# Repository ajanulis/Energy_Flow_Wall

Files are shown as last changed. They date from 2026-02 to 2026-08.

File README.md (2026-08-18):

# Energy Flow Wall (Public)

Public hardware/reference repository for the Energy Flow Wall mesh-networked
ventilation valve system, organized by subsystem:

```
Actuator/   Window-frame-mounted valve unit — KiCad PCB designs, Fusion 360 case, manuals
Gateway/    Raspberry Pi + NC1000 mesh gateway — NeoCortec protocol docs
Device/     In-room e-paper touchscreen — hardware planning, procurement, datasheets, working-prototype photos
Docs/       Whole-system docs (functional requirements, architecture reference)
```

Source code (firmware, Gateway pipeline, Node-RED deploy scripts) is
maintained in a separate private repository.

---

## Actuator

The window-frame-mounted unit itself — PSoC5 + NC1000 mesh radio + motors + flaps + fan.

- [`Actuator/KiCad/`](Actuator/KiCad/) — PCB designs.
- [`Actuator/Actuator_EFW#4_based_on_8411A v4_non_symmetrical_case.f3d`](<Actuator/Actuator_EFW%234_based_on_8411A%20v4_non_symmetrical_case.f3d>) — Fusion 360 mechanical design (non-symmetrical case, v4). Open with Autodesk Fusion 360; all parametric history included. [Direct download](<https://github.com/ajanulis/Energy_Flow_Wall/raw/main/Actuator/Actuator_EFW%234_based_on_8411A%20v4_non_symmetrical_case.f3d>).
- [`Actuator/Manuals/DK_USER_MANUAL.md`](Actuator/Manuals/DK_USER_MANUAL.md) — End-user manual for the shipped demo unit: setup, dashboard usage, Demo Mode, troubleshooting.
- [`Actuator/Manuals/COMMANDS.md`](Actuator/Manuals/COMMANDS.md) — Developer/integrator reference: MQTT topics, JSON request format, full firmware command set, timeouts.

**Hardware**: PSoC 5 (CY8C5888LTQ-LP097) · DRV8411A motor driver · NC1000 mesh radio · UART 115200 baud.

## Gateway

Raspberry Pi 5 + NC1000 daughterboard, running NeoGateway + Node-RED +
the MQTT⇌mesh pipeline.

- [`Gateway/KiCad/Gateway_PCB/`](Gateway/KiCad/Gateway_PCB/) — the RPi/NC1000 HAT PCB design (moved here from `Actuator/KiCad/`, where it was previously grouped by mistake).
- [`Gateway/NeoCortec/`](Gateway/NeoCortec/) — NeoCortec integration manual, NC1000 datasheet, and UART communication spec — the protocol reference the Gateway pipeline implements against.

## Device

In-room e-paper touchscreen display. Custom PCB is still in the planning
stage, but a working touchscreen dashboard already runs end-to-end on an
STM32U5 Nucleo — see [`Device/README.md`](Device/README.md) for photos
and a walkthrough of what it does.

- [`Device/README.md`](Device/README.md) — working-prototype photos + what it does. **Start here.**
- [`Device/Brief.md`](Device/Brief.md) — architectural decisions + concept/scope.
- [`Device/Procurement.md`](Device/Procurement.md), [`Device/Datasheet_Stash.md`](Device/Datasheet_Stash.md) — parts sourcing and reference datasheets.
- [`Device/HW_Prep.md`](Device/HW_Prep.md), [`Device/Doc_Gaps.md`](Device/Doc_Gaps.md) — bring-up prep notes and known documentation gaps.

## Docs (whole-system)

- [`Docs/SYSTEM_REFERENCE.md`](Docs/SYSTEM_REFERENCE.md) — high-level system reference (architecture, mesh layout).
- [`Docs/EFW_Functional_Requirements_1.md`](Docs/EFW_Functional_Requirements_1.md) — original functional requirements document.

---

**Questions?** Contact the repository owner.

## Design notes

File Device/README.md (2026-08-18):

# Device — In-Room User-Facing Mesh Node

This directory holds the design intent, prep work, procurement notes, and
working-prototype progress for the **EFW Device** — the third node type
in the Energy Flow Wall mesh, alongside the Gateway (RP5 + NeoGW) and the
Actuator (flap motors).

**Status:** custom PCB not yet designed (all schematic decisions are
locked at the architectural level, PCB layout is the next step), but a
working touchscreen dashboard is already running end-to-end on an
STM32U5 Nucleo dev board over the real mesh — see below.

## Working prototype

| Auto mode | Manual override |
|---|---|
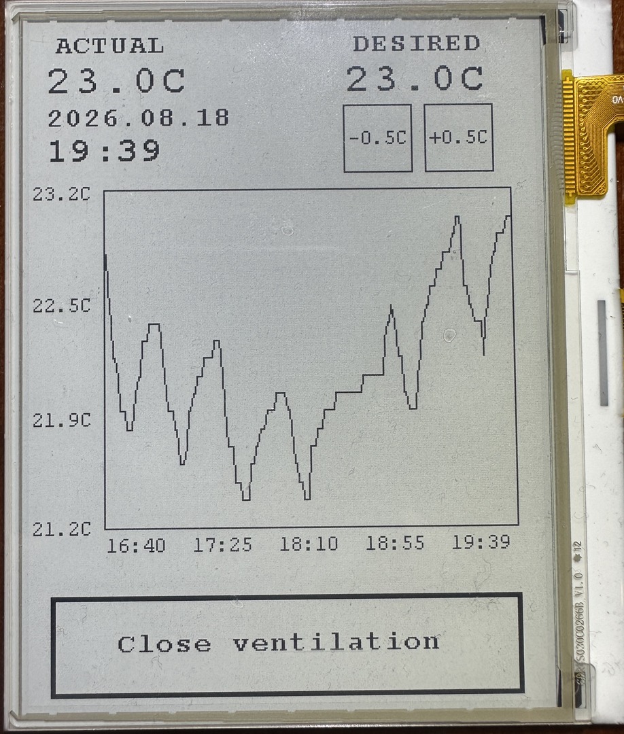
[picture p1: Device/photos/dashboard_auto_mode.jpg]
Dashboard in auto mode
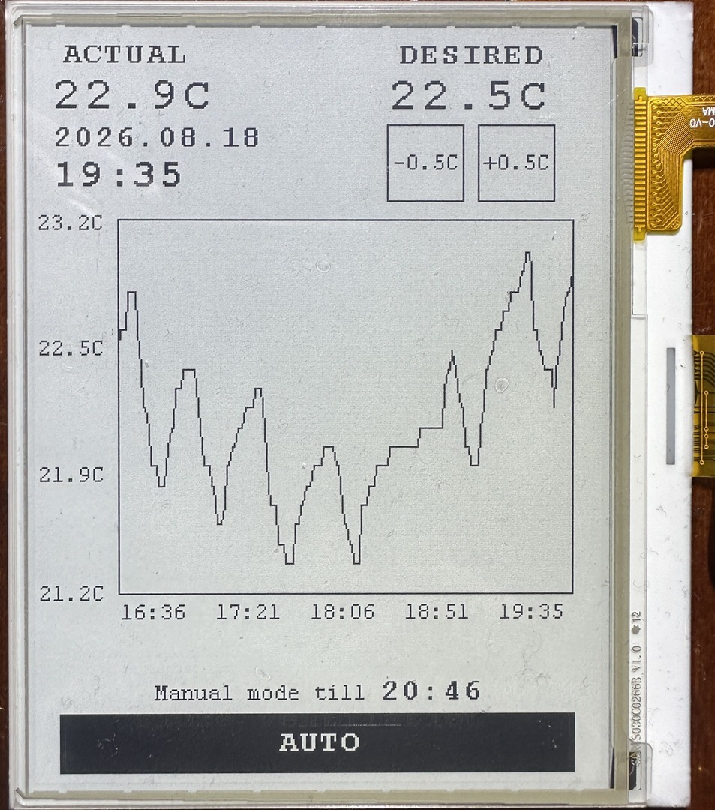
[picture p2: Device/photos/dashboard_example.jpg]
Dashboard in manual mode
|  |  |
| Valve following its normal schedule — tall **"Close ventilation"** button offers to override it. | A manual override active (here, from a DESIRED nudge) — short **"AUTO"** button, with the till-time shown, cancels it. |

A 4.2" e-paper touchscreen (GDEY042T81, FT6336U touch) on an STM32U5
Nucleo, talking to the mesh over a NeoCortec NC1000 radio. In-room
display + manual override panel for one valve zone — no phone or laptop
needed to see the current temperature or flip into manual mode.

**What it shows:**
- **ACTUAL** — the room's current temperature, live from the mesh.
- **DESIRED** — the target temperature; tap `-0.5C` / `+0.5C` to nudge it.
- **Date / time** — synced live, every ~30s.
- **Chart** — a live temperature history kept on-device: tap the top of
  the chart to zoom out (3h → 6h → 12h → 24h → 48h → 7d), the bottom to
  zoom back in, and the left/right halves to scroll back/forward in time.
- **Valve button** — the black bar along the bottom, showing either
  "Close ventilation" (Auto mode) or "AUTO" + a manual-override till-time.

Firmware source, build/flash instructions, and a fuller writeup live in
the private code repo (see below) — this directory is progress notes and
photos only.

## What the Device is

A battery-powered in-room sensor and user-interface node:

- 4.2" 400×300 monochrome e-paper with bonded capacitive touch overlay (GoodDisplay GDEY042T81-T02 + FT6336U)
- STM32U585 (ARM Cortex-M33 @ 160 MHz, 2 MB flash)
- NeoCortec NC1000 sub-GHz mesh + Bluetooth Low Energy
- Modular sensor population per install: temperature / humidity always (Sensirion SHT45), CO₂ optional (Sensirion SCD41), human presence optional (Infineon BGT60LTR11AIP 60 GHz radar), 2 in / 2 out potential-free I/O optional
- LiFePO₄ pouch battery (LFP143060, 1800 mAh) with MagSafe wireless charging (TI BQ51013B)
- Optional accessory: small solar panel + TI BQ25570 MPPT energy harvester

The Device replaces the retired 0x33 / 0x44 NC1000-only test-only T/H sniffers.

## Files in this directory

| File | What's in it |
|---|---|
| [Brief.md](Brief.md) | Architectural decisions — display, power, sensors / I/O, mesh integration, all locked component choices and the rationale. **Read this first.** |
| [Schematic_placeholder.md](Schematic_placeholder.md) | Authoritative-schematic file (placeholder until hardware exists). |
| [HW_Prep.md](HW_Prep.md) | Toolchain setup, reading order for the datasheets, and the firmware skeleton work that can be done without hardware in hand. |
| [Procurement.md](Procurement.md) | Tiered dev-kit shopping list with prices and rationale. |
| [Doc_Gaps.md](Doc_Gaps.md) | Datasheet gaps still to grab + TBD part choices that block the schematic. |
| [Datasheet_Stash.md](Datasheet_Stash.md) | Pointer to the local datasheet stash (path is on the author's machine; the third-party PDFs themselves are not in this repo). |
| [LFP_Pouch_Sources.md](LFP_Pouch_Sources.md) | Verified LFP pouch cell suppliers for the Device battery. |
| [Sniffer_Concept.md](Sniffer_Concept.md) | Exploratory concept for a future mains-powered premium air-quality variant on the same mesh. Not yet committed. |
| `scripts/grab_datasheets.py` | Idempotent downloader for the Device datasheets. |
| `scripts/DOWNLOADS_TODO.md` | List of files that need to be downloaded manually (gated PDFs, login walls, CDN-fighting-curl, etc.). |
| [`Docs/02_Display_Touch/READ_FIRST.md`](Docs/02_Display_Touch/READ_FIRST.md) | Porting strategy for the GoodDisplay GDEY042T81-T02 reference firmware (STM32F103) to the STM32U585 production target. |
| `Docs/DOWNLOADS_TODO.html` | HTML rendering of `scripts/DOWNLOADS_TODO.md`. |

The `Docs/` subdirectory holds annotations about external reference materials kept locally; the third-party datasheets and vendor sample-code archives themselves are not in this repo for licensing and repo-size reasons.

## Sibling content in this repo

- [`../Actuator/KiCad/Main_PCB_Based_on_8411A/`](../Actuator/KiCad/Main_PCB_Based_on_8411A/) — the Actuator KiCad design (sibling node, useful reference).
- [`../Docs/`](../Docs/) — system-level documentation (SYSTEM_REFERENCE, EFW_Functional_Requirements, etc.).
- [Energy_Flow_Wall_Code](https://github.com/ajanulis/Energy_Flow_Wall_Code) — private firmware + scripts repo; Device firmware (build/flash instructions, full technical writeup) lives there under `firmware/device/epaper_bringup/`.

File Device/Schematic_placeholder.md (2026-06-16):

# Device Schematic — Authoritative Reference (PLACEHOLDER)

**Status: hardware not yet designed.** Nothing in this file is ground truth yet.

When the Device PCB + MCU TopDesign exist, this file gets populated the same way `schematic-actuator` (internal note) was — written page-by-page from the actual PDF schematic together with Aidas. Do NOT infer schematic topology from code, synthesis reports, or assumptions — only from the PDF or Aidas confirmation.

Until then, design intent lives in [Brief](Brief.md). Open hardware questions to resolve before this file can be written:

- ~~MCU choice~~ — **decided 2026-06-15**: STMicroelectronics **STM32U585CIU6** (QFN-48, Cortex-M33 @ 160 MHz, 2 MB flash, 786 KB RAM). See `device_brief.md` for rationale. Schematic will document final peripheral pin assignments (SPI for e-paper + radar, I²C for SCD41 + GT911 touch, USART for NC1000 CTS-wake, GPIO for opto-in / MOSFET-out, ADC for battery monitor).
- E-paper panel model + controller + SPI pin map + refresh timing
- CO₂ sensor candidate (SCD41 / SCD30 / SGP41) and its I²C bus sharing with SHT45
- Presence sensor type (PIR binary vs. mmWave continuous)
- Potential-free I/O channel count, isolation, max voltage/current
- Touch button mechanism (cap-touch direct to MCU vs. dedicated controller)
- LiFePO₄ pack: cell count, BMS, charge current, MagSafe coil + receiver IC selection
- Solar input topology (when populated) and its interaction with the wireless-charge path
- Magnet layout for MagSafe alignment + how it coexists with NC1000 antenna routing

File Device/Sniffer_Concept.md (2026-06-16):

# Sniffer — Future Premium Air-Quality Variant (EXPLORATORY)

**Status: concept only.** Not yet a committed product. Captured here so the idea isn't lost when the [Brief](Brief.md) decided "SCD41 only, leave full AQ out of the Device base SKU".

## Role
Standalone indoor air-quality monitor that joins the same NC1000 mesh as Device, Actuator, and Gateway. Use case: rooms where the customer wants full IAQ visibility (PM, VOC, NOx in addition to CO₂ + T/H), and where that data can also influence flap behavior on the Actuator via the Gateway.

Distinct from Device because:
- **Mains-powered** — no LiFePO₄ / MagSafe constraints, so fan-driven sensors are fine.
- **AQ-first** — display may or may not be present; the value-add is the sensor suite, not the user interface.
- **Different enclosure mechanics** — needs intake/exhaust airflow paths.

## Sensors (initial concept)
- **Sensirion SEN6x** — combined module covering CO₂ + T + RH + VOC + NOx + PM. Exact variant (SEN66 with CO₂, SEN65 without, SEN63C without NOx) TBD by feature target.
- **Bosch BMV080** — optional. **Fan-less laser PM1/PM2.5 sensor** (no moving air required). Could either replace SEN6x PM (run SEN6x fan-disabled for the gas sensors only, use BMV080 for PM) — quieter, lower power, smaller enclosure — or run alongside as redundancy. Decide based on power-vs-accuracy testing.

## Power & enclosure
- Mains-powered (USB-C PD or barrel jack TBD).
- Continuous operation, no aggressive sleep.
- Enclosure must accommodate fan airflow if SEN6x is the PM source. If BMV080 replaces PM in SEN6x, fan can stay off → much quieter, smaller enclosure possible.

## Mesh integration
- Same NC1000 + AAPI as Device and Actuator.
- New node-ID class TBD.
- Reports periodic AQ readings to Gateway in Normal mode. Could accept commands in ALT mode (e.g. force-measurement, calibration).

## Open questions (don't burn cycles on these until Device is shipping)
1. Is Sniffer a separate PCB or a populate-variant of the Device PCB? Device PCB already has PSoC6 + NC1000 + display + CapSense — adding SEN6x + BMV080 as a populate option could keep the SKU count low. But airflow paths in the Device enclosure may be incompatible with the wall-flush aesthetic, forcing a separate enclosure.
2. Does Sniffer need its own display, or just a status LED?
3. SEN6x variant choice — SEN66 (with CO₂) vs SEN65 (without, paired with separate SCD41) vs SEN63C (no NOx).
4. BMV080 — confirmed availability, evaluation board, accuracy vs SEN6x PM at low duty cycle, power figures from datasheet.

## Linked
- [Brief](Brief.md) — the base SKU that this product extends
- `schematic-actuator` (internal note) — reference for what an authoritative schematic file should look like

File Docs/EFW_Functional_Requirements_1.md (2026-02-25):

# Energy Flow Wall (EFW) — Functional Requirements Document

**Version:** 0.8  
**Last Updated:** 2026-02-24  
**Status:** Draft

---

## 1. System Overview

The Energy Flow Wall (EFW) is a smart building ventilation system designed to automate ventilation valves for energy-efficient airflow control. The valves are incorporated into the top sash of the window and controlled by motorised actuators. The system uses a wireless mesh network to coordinate actuator nodes, enabling automated and remote control of valve positions to optimise indoor air quality, thermal comfort, and energy consumption. Efficacy testing has been conducted by the Fraunhofer Institute (Germany) and Aalborg University (Denmark).

---

## 2. Architecture

### 2.1 Network Topology

- **Mesh Protocol:** NeoCortec NC1000 mesh networking
- **Gateway:** NeoGateway software running on Raspberry Pi 5, hardwired to one NC1000 module
- **Node Types:** Actuator nodes, Device nodes

```
[Raspberry Pi 5 + NeoGateway]
        |
    [NC1000] ─── (mesh) ─── [NC1000] ─── [NC1000]
                               |               |
                          [PSoC CY8C5888]  [Device Node]
                          [Motor A] [Motor B]
```

### 2.2 Node Types

#### 2.2.1 Gateway Node
- **Hardware:** Raspberry Pi 5 in Argon One V5 Casted Aluminium case
- **Storage:** 256 GB NVMe SSD via Argon NVMe expansion board (faster boot, more reliable than microSD)
- **Wireless module:** NeoCortec NC1000-8 (868 MHz), external antenna mounted on Argon One V5 case
- **Display:** External mini OLED — shows IP address, CPU temperature, CPU core loads, memory utilisation
- **UPS:** Argon One V5 UPS planned (listed in Argon manuals, not yet available to order)
- **Software:** NeoGateway, Node-RED (automation logic), MQTT (message broker), Grafana (monitoring/visualisation)
- **Role:** Bridge between mesh network and higher-level control/monitoring systems
- **Interfaces:** UART to NC1000-8, Ethernet/WiFi for upstream connectivity

#### RPi ↔ NC1000-8 Wiring (4-wire)

| Signal | RPi 40-pin Header Pin |
|---|---|
| NC1000 nReset | Pin 18 |
| NC1000 RX | Pin 24 |
| NC1000 TX | Pin 21 |
| NC1000 CTS | Pin 19 |

#### 2.2.2 Actuator Node
- **Hardware:** NC1000 + Cypress CY8C5888LTQ PSoC
- **Interface:** NC1000 to PSoC via UART — 3 signals: **RX, TX, CTS**. CTS used as wake signal for PSoC and as ready-to-communicate indicator from NC1000
- **Role:** Dual motor control for window flaps + fan PWM control
- **Motors:** 2 per node (Motor A, Motor B) — rotate flaps to open/close air pathways
- **Fan:** PWM-controlled via Port 3
- **Feedback:** Quadrature encoder per motor
- **Protection:** Overcurrent detection per motor
- **Power:** Battery-powered; PSoC in deep sleep during Normal mode, wakes on UART activity

#### 2.2.3 Device Node
- **Hardware:** TBD
- **Role:** TBD (sensors, switches, or other peripherals)

---

## 3. Functional Requirements

### 3.1 Gateway

| ID | Requirement | Priority | Status |
|----|---|---|---|
| GW-01 | Gateway shall receive and forward commands from upstream system to mesh nodes | High | Draft |
| GW-02 | Gateway shall relay status/telemetry from mesh nodes to upstream system | High | Draft |
| GW-03 | Gateway shall maintain persistent UART connection to local NC1000 module | High | Draft |
| GW-04 | Gateway shall support reconnection on UART failure | Medium | Draft |
| GW-05 | Gateway shall log mesh traffic for diagnostics | Low | Draft |

### 3.2 Actuator Node

| ID | Requirement | Priority | Status |
|----|---|---|---|
| AC-01 | Actuator shall receive motor commands via NC1000 wireless mesh | High | Draft |
| AC-02 | Actuator shall control two independent motors (Motor A, Motor B) via DRV8411A | High | Draft |
| AC-03 | Actuator shall track motor position using quadrature encoder feedback | High | Draft |
| AC-04 | Actuator shall detect and respond to overcurrent conditions per motor | High | Draft |
| AC-05 | Actuator shall report actual motor positions back through mesh after movement | High | Draft |
| AC-06 | Actuator shall execute position commands with configurable speed/ramp | Medium | Draft |
| AC-07 | Actuator shall support emergency stop command | High | Draft |
| AC-08 | Actuator shall retain last known motor positions on power cycle | Medium | Draft |
| AC-09 | PSoC shall remain in deep sleep during Normal mode | High | Draft |
| AC-10 | PSoC shall wake on CTS pin assertion by NC1000 | High | Tested |
| AC-11 | PSoC shall transmit current motor positions immediately on wake | High | Draft |
| AC-12 | PSoC shall not transmit to NC1000 until CTS is asserted | High | Tested |
| AC-13 | Actuator shall accept and execute fan PWM control commands | Medium | Draft |
| AC-14 | Actuator shall report position even if target not reached (mechanical fault) | High | Draft |

### 3.3 Device Node

| ID | Requirement | Priority | Status |
|----|---|---|---|
| DV-01 | TBD | - | Draft |

---

## 4. Communication Protocol

### 4.1 Physical Layer

- **Gateway ↔ NC1000:** UART (hardwired)
- **PSoC ↔ NC1000:** UART (hardwired), AAPI protocol
- **NC1000 ↔ SHT45:** Native NC1000 interface (no PSoC involvement)
- **Node ↔ Node:** NC1000 wireless mesh (NeoCortec proprietary)

### 4.2 Node ID Scheme

| Node Type | Node ID (Hex) |
|---|---|
| Gateway | 0x0010 |
| Actuator 1 | 0x0011 |
| Actuator 2 | 0x0012 |
| Actuator N | 0x0010 + N |
| Device nodes | TBD |

### 4.3 Mesh Operating Modes

### 4.3 Mesh Operating Modes

#### Normal Mode
- NC1000 on each node autonomously reads T & H data from SHT45
- Data is periodically transmitted to Gateway (Node ID 0x0010)
- PSoC is in deep sleep (power preservation — battery-powered nodes)
- Applies to both Actuator and Device nodes
- Future: CO2 sensor data to be added

#### Alternative Mode
- **Trigger:** Initiated by Gateway when monitored environmental thresholds are exceeded:
  - Temperature exceeds set limit, OR
  - Humidity exceeds set limit
  - Future: CO2 level exceeds set limit
- **Scope:** Entire mesh switches mode simultaneously (not per-node)

- **Activation sequence:**
  1. Gateway broadcasts switch to Alternative mode — entire mesh transitions
  2. NC1000 switches to UART mode on all nodes
  3. PSoC wakes up (triggered by NC1000 UART activity)
  4. On wake-up, PSoC immediately transmits current motor positions via UART ports
  5. PSoC parses incoming commands from Gateway:
     - New motor position commands (Motor A, Motor B)
     - Fan PWM level command
  6. PSoC executes received commands (motor movement, fan adjustment)
  7. Actuator reports actual achieved motor positions back to Gateway
     - Position may differ from commanded if mechanical obstruction or failure occurred
  8. Gateway switches entire mesh back to Normal mode
  9. PSoC returns to deep sleep
  10. Nodes resume periodic T & H (and future CO2) data collection

- **Timeout / retry handling:**
  - If Gateway does not receive motor position report after command, it waits 10 seconds
  - After 10 seconds, Gateway re-initiates Alternative mode (NC1000 switches to UART again)
  - PSoC waking up on UART activity should be sufficient to trigger position retransmission

#### Mode Transition Diagram
```
[Normal Mode] ──── threshold exceeded ────► [Alternative Mode]
    ▲                                              │
    │                                   NC1000 → UART mode
    │                                   PSoC wakes up
    │                                   PSoC sends positions
    │                                   Gateway sends commands
    │                                   Motors/Fan move
    │                                   PSoC reports positions
    │                                              │
    │         no response? wait 10s, retry Alt ───►│
    │                                              │
    └──────────── Gateway resets to Normal ────────┘
```

#### PSoC Power Management
- PSoC is in deep sleep during Normal mode (battery-powered)
- **Wake signal: CTS pin** — NC1000 asserts CTS when it transitions to UART mode (Alternative mode entry)
- PSoC ↔ NC1000 physical interface: **3 signals — RX, TX, CTS**
- On wake: PSoC immediately transmits current motor positions, then parses incoming commands
- Return to sleep: when mesh returns to Normal mode

> **Note:** NC1000 also sleeps most of the time and will not respond to any commands until it wakes up and asserts CTS. CTS must be monitored before any UART transmission is attempted in both directions — PSoC must not transmit until CTS is asserted by NC1000.

#### NC1000 UART Port Assignment

| Port | Assignment |
|---|---|
| Port 0 | Reserved |
| Port 1 | Motor A position |
| Port 2 | Motor B position |
| Port 3 | Fan PWM control |

### 4.4 AAPI Protocol (NC1000 ↔ PSoC)

- Protocol used for communication between NC1000 module and PSoC firmware
- Commands received by NC1000 are forwarded to PSoC via AAPI over UART
- Known issue: "one packet delay" — response to a command arrives one packet late; must be accounted for in parsing logic
- AAPI parsing must handle complete packet detection before command execution

### 4.5 Command Reference

| Command | Direction | Description | Status |
|---|---|---|---|
| MOTOR_A_MOVE | Gateway → Actuator | Move Motor A to target position | Draft |
| MOTOR_B_MOVE | Gateway → Actuator | Move Motor B to target position | Draft |
| MOTOR_STOP | Gateway → Actuator | Emergency stop both motors | Draft |
| STATUS_REQ | Gateway → Actuator | Request current actuator status | Draft |
| STATUS_RESP | Actuator → Gateway | Motor positions, states, faults | Draft |

*(To be expanded)*

---

## 5. Hardware Reference

### 5.1 Key Components

| Component | Part | Role |
|---|---|---|
| Microcontroller | Cypress CY8C5888LTQ (PSoC 5LP) | Motor control, encoder reading, fault detection |
| Wireless module (Actuator/Device) | NeoCortec NC1000 | Mesh networking + native SHT45 interface |
| Wireless module (Gateway) | NeoCortec NC1000-8 (868 MHz, external antenna) | Mesh gateway radio |
| T&H Sensor | Sensirion SHT45 | Temperature & humidity, read natively by NC1000 |
| Motor driver | Texas Instruments DRV8411A | Dual H-bridge motor drive |
| Gateway hardware | Raspberry Pi 5 + Argon One V5 case + NVMe 256 GB | NeoGateway host |
| Gateway software | NeoGateway | Mesh-to-upstream bridge |
| Gateway display | Mini OLED | Local diagnostics (IP, CPU temp, load, memory) |

### 5.2 PSoC Peripherals Used

- Dual PWM for motor drive
- Quadrature Decoder (x2) for encoder feedback
- UART for NC1000 communication
- ADC or comparator for overcurrent sensing

### 5.3 Motor Drive

- **Driver IC:** Texas Instruments DRV8411A (dual H-bridge)
- One DRV8411A drives both Motor A and Motor B on the Actuator node

---

## 6. Known Issues / Development Notes

| ID | Area | Description | Status |
|----|---|---|---|
| DEV-01 | AAPI/UART | "One packet delay" in UART communication — response arrives one cycle late | Resolved / Workaround in place |
| DEV-02 | AAPI | Proper packet boundary detection required before command execution | In progress |
| DEV-03 | Mesh | NC1000 mesh throughput limited — avoid high-frequency polling | Noted |

---

## 7. Open Questions

- What sensors or peripherals are planned for Device nodes beyond SHT45?
- DRV8411A control mode: IN/IN vs PH/EN?
- Target response time for actuator commands in Alternative mode?
- Mesh network size — number of Actuator/Device nodes expected?
- What are the specific threshold values for T, H (and future CO2) that trigger Alternative mode?
- Motor position units — encoder counts, degrees, or percentage of travel?
- Fan PWM range and resolution?

---

## 8. Revision History

| Version | Date | Changes |
|---|---|---|
| 0.1 | 2026-02-24 | Initial draft |
| 0.2 | 2026-02-24 | Added DRV8411A, SHT45, mesh modes, node ID scheme |
| 0.3 | 2026-02-24 | Added RPi software stack, Alternative mode flow, fault handling |
| 0.4 | 2026-02-24 | Added PSoC sleep/wake, fan control, NC1000 UART port assignments, 10s retry logic |
| 0.6 | 2026-02-24 | Corrected system overview: ventilation valve in window sash, added energy reduction goal and research partners |
| 0.7 | 2026-02-24 | Gateway hardware detailed: Argon One V5 case, NVMe 256GB, NC1000-8 at 868MHz, OLED display, planned UPS |
| 0.8 | 2026-02-24 | Added RPi ↔ NC1000-8 4-wire pin mapping (nReset, RX, TX, CTS) |

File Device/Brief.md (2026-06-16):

# Device — EFW Third Node Type

**Role:** in-room user-facing node. Long-term **replacement** for the test-only 0x0033 (Outside) and 0x0044 (Car) NC1000-only T/H sniffers — those were proof-of-concept, not production. Production EFW mesh: **Gateway** (RP5 + NeoGW) + **Actuator** (flap motors) + **Device** (this).

Still part of the same EFW project. Same GitHub repos (`Energy_Flow_Wall` for hardware, `Energy_Flow_Wall_Code` for firmware/scripts).

## Display
- ✅ **GoodDisplay GDEY042T81-T02** — 4.2" monochrome e-paper, **400 × 300 px**, SPI, SSD1683 controller, **with bonded PET capacitive touch overlay** driven by **FT6336U (FocalTech)** controller — I²C address 0x38, with IRQ + RST lines. The touch overlay replaces the originally planned MCU-native CapSense — UI elements are rendered on the e-paper and respond to direct touch, freeing the front face of physical control area and giving firmware the flexibility to evolve the UI over OTA without hardware changes. **GoodDisplay supplies STM32 reference code for both panel and touch driver** (good-display.com/product/473.html → Downloads → "GDEY042T81-FT02/GDEY042T81-T02 STM32 Sample Code") — significant bring-up shortcut.
- Chosen for lowest power of the modern partial-refresh-capable family: full refresh ~2 s / partial refresh ~0.3 s, deep-sleep current <5 µA, refresh energy small enough that even a 1-minute time-chip update path is essentially free in the battery budget. 4.2" is "decent size" — 137 PPI, comfortable at arm's length.
- Square 480×480 was the original aim (a colour TFT mock was prototyped at that resolution, NSPanel Pro-class) but **true 4" 480×480 SPI e-paper isn't a stock part in 2026** — the square e-paper market only exists at sub-2" sizes and at ≥5.83" (and the closest 5.83" candidate is going EOL). 400×300 lands the same physical size without custom-panel MOQ pain.
- **UI consequence**: the colour TFT prototype mock needs to be re-rendered at 400×300 (landscape 4:3) before it represents what the Device will actually show in monochrome e-paper. The two-card top + chart-below layout still fits; fonts and chart height shrink. Easy port. (An e-paper preview mock has also been prototyped at the same physical size.)
- Refresh strategy: partial refresh for time-chip + setpoint changes (sub-second, no full-screen flicker); full refresh once an hour or on full-screen state changes to clear ghosting.

## Power
- **LiFePO₄ battery.** Chemistry chosen for long cycle life + safe nominal voltage near the load rail.
- **Wireless charging via MagSafe** — receiver coil + magnets embedded in the Device. End-user lifts the Device off the wall every 6–12 months, drops on any MagSafe pad, returns it.
- **Room-side fixture:** **3D-printed plastic holder** with a **second AliExpress 18-magnet adhesive ring** stuck face-out — symmetric two-ring magnet pairing roughly doubles the pull-force vs. a magnet-to-steel configuration, and the N-S alternating polarity pattern on both rings auto-aligns rotationally when faces oppose. A **shallow perimeter lip** on the fixture provides redundant translational location so the Device snaps into a defined position. No steel parts in the wall fixture — RF-clear everywhere except the small magnet footprints.
- **Display orientation**: landscape (native 4:3 e-paper, no firmware rotation cost).
- ✅ **Battery cell**: **LFP143060** — stock LFP pouch, 1800 mAh, 3.2 V nominal, **14 × 30 × 60 mm**, integrated protection PCB, 2000+ cycles. Source: [lithium-lifepo4-battery.com](https://www.lithium-lifepo4-battery.com/lifepo4-battery-lfp143060-1800mah-3-2v/), sample MOQ 5–10 pcs / 3–5 day lead. The capacity is encoded in the PN (LFP / 14 mm thick / 30 mm wide / 60 mm long). Backup suppliers if that vendor is unreachable: **Grepow** (grepow.com/lifepo4-battery.html — well-established Shenzhen maker, full LFP pouch range), **Misen Power** (misenpower.com — explicit LFP pouch line).
- **Mechanical envelope** (working assumption): Device front face ~100 × 80 mm, total depth ~19–22 mm (e-paper 1.2 + PCB 1.6 + LFP pouch 14 + Qi coil/magnet ring stacked beside the pouch + enclosure back 1.5). Comparable to a chunky light-switch plate. Adjust when first 3D draft exists.
- **Sleep budget is very tight.** Whatever the NC1000 1/sec ALT-mode wake mystery turns out to be on Actuator (open FRD item), it likely matters more here. Solving it is a prerequisite for shipping the Device.
- **Optional small solar panel — separate "PV module" SKU.** PV cell + **TI BQ25570** harvester (MPPT + boost + LiFePO₄ charge management, integrated single-chip solution) + support passives all live on the PV module, not the Device PCB. Two-wire output (regulated ~3.45 V at BQ25570 termination) plugs into the Device via a small connector; on the Device side it's just one connector, a Schottky reverse-protection diode, and a filter cap — feeds the same LiFePO₄ charge node as the BQ51013B MagSafe path. Either source (MagSafe or PV) can charge concurrently; higher-voltage source wins, no fight. Extends charge interval; in bright-room installs may eliminate manual MagSafe charging entirely. Same PV module potentially reusable for a future [Sniffer Concept](Sniffer_Concept.md) product.

## Sensors / I/O — modular, populate per install
Single board family, single firmware family — each unit assembled only with the modules the room actually needs:
- **Temperature + Humidity** — always populated. **Sensirion SHT45** wired **directly to NC1000 I²C** — same topology as Actuator. NC1000 reads SHT45 and reports to Gateway autonomously in Normal mode without ever waking the MCU. Display T/H is pulled from the Gateway store via the STM32 ↔ NC1000 UART when the screen refreshes (not on every NC1000 read).
- **CO₂** — optional. **Sensirion SCD41** (photoacoustic NDIR, I²C, single-shot ~50 µJ mode compatible with hibernate). Premium air-quality variant with SEN6x + Bosch BMV080 spun off as a separate mains-powered product — see `sniffer_brief.md`.
- **Presence / occupancy** — optional. **Infineon BGT60LTR11AIP** — 60 GHz low-power radar (single-target presence/motion). µW-range sleep, much better than mmWave dev boards and far richer than a PIR. SPI control + interrupt output.
- **Potential-free I/O** — optional. **2 inputs + 2 outputs.** Inputs: optocoupler-isolated (LTV-356T / PC817 family), accept 3–24 V dry-contact or low-voltage logic from external systems. Outputs: low-side N-MOSFET (e.g. DMG2305UX or similar), open-drain to GND, customer's load wired between external rail and the output pin; rated for ≤24 V external rail, ≤500 mA. Targets thermostat-style dry-contact inputs on underfloor-heating zone controllers, whole-house extraction-fan starters, and HVAC AHU thermostat inputs — not direct mains switching (a separate external relay block handles that 5% of cases). Connector: 4-pole 3.5 mm-pitch screw terminal block at PCB bottom edge.
- **Touch input** — **integral to the e-paper display** (no separate PCB area). **FT6336U (FocalTech)** capacitive touch controller bonded on top of GDEY042T81-T02, communicating with MCU over I²C (shared bus with SCD41 — addresses don't conflict: **0x38** vs 0x62) + IRQ + RST pins. Wakes the MCU on touch from deep sleep; on-screen tap targets are drawn in firmware and can evolve over OTA. GoodDisplay supplies an STM32 reference driver — start there rather than writing the FT6336U I²C driver from scratch.

The "populate only what's needed" approach keeps SKU count low without ecosystem fragmentation: same PCB, same firmware, modules absent → corresponding features simply unavailable in that unit.

## Mesh integration
- Same NC1000 radio as Actuator and as the legacy test devices.
- Same AAPI protocol on the same gateway.
- **New node IDs** to be assigned. Do NOT reuse 0x33 / 0x44 — they were ad-hoc test IDs, retired.
- Operates in **Normal mode** for T/H reporting (like 0x55 Actuator does) and in **ALT mode** to receive commands (display update, output toggle, etc.) and to send local user input (touch button events, presence changes).

## Decisions made (2026-06-14, MCU revised 2026-06-15)
- ✅ **MCU**: **STMicroelectronics STM32U585CIU6** (QFN-48, Cortex-M33 + TrustZone @ 160 MHz, **2 MB flash, 786 KB RAM**, OctoSPI for future external flash if ever needed). Chosen after walking away from PSoC6:
  - PSoC Creator tooling is in maintenance mode at Infineon and ModusToolbox is the forced successor — uncertain long-term investment in the PSoC line post-acquisition.
  - The PSoC6 features that originally justified it (native CapSense block) became irrelevant once we moved to **GT911 touch overlay on the e-paper**; the touch is in the panel, not in the MCU.
  - STM32U5 is ST's current strategic ultra-low-power line — multi-decade roadmap, native macOS tooling (STM32CubeIDE + VSCode + STM32-PlatformIO), much larger community, no vendor account required.
  - **2 MB flash is the right size**, not overkill: realistic firmware budget once LVGL + 3 fonts + room icons + multi-room data + daily/weekly schedule + safe OTA double-bank is included is ~900 KB minimum, comfortable target ~1.4 MB. 256 KB-class chips would force feature compromises within ~12 months.
  - Hand-solderable QFN-48 package — no BGA respin step.
- ✅ **T/H sensor**: SHT45 (same as Actuator).
- ✅ **CO₂ sensor**: Sensirion **SCD41**. (Full air-quality coverage is the future Sniffer product, not the Device.)
- ✅ **Presence sensor**: Infineon **BGT60LTR11AIP** 60 GHz LP radar.
- ✅ **Touch input**: **FT6336U (FocalTech) capacitive touch controller** bonded on the e-paper (GDEY042T81-T02 variant). I²C address 0x38 (no conflict with SCD41 at 0x62). Replaces the originally planned MCU-native CapSense. Frees the front face of physical control area and lets UI evolve in firmware over OTA. **GoodDisplay supplies STM32 reference code** for both panel + touch — meaningful bring-up shortcut.
- ✅ **SHT45 bus topology**: SHT45 → NC1000 I²C (autonomous). STM32 has no electrical path to SHT45; pulls T/H from Gateway via UART only when display refreshes.
- ✅ **Battery target**: **LiFePO₄ 3.2 V / 1800 mAh**. SHT45-only mesh beacon should run for years on this; full-load (CO₂ + radar + touch + e-paper) should comfortably exceed the 6–12 month MagSafe charge interval. See **Power budget** section below.
- ✅ **CO₂ measurement cadence — presence-gated state machine**:
  - **5 min** baseline when room is **occupied** (presence detected by BGT60LTR11AIP radar within the last *N* minutes — tune *N* during bring-up, start with 10 min).
  - **30 min** (or longer) when room is **unoccupied AND CO₂ already at baseline** (e.g. below 500–600 ppm or within ±100 ppm of the last unoccupied minimum). No new CO₂ source is in the room — nothing meaningful is changing.
  - **5 min** stays active when room is **unoccupied AND CO₂ still elevated** — we want to watch the decay curve as ventilation clears the room.
  - **Snap back to 5 min the instant** the radar reports new presence — don't wait for the next scheduled tick.
  - **10 s** during development / bench validation only.
  - **Why this matters for battery**: SCD41 single-shot is the dominant active-power draw in a fully-populated Device (~250 µA averaged at 5 min cadence). Stretching to 30 min in unoccupied + baseline state cuts that contribution by ~6×, materially extending the MagSafe-charge interval for installations like storage rooms, roof cavities, garages, and any other "Actuator integrated but no human" rooms Aidas described.
  - **Falls back gracefully**: in a Device populated *without* the radar module, the firmware simply uses the 5-min cadence unconditionally — no special-case code, just a "presence reported?" check that defaults to "yes, unknown".
- ✅ **Wireless charging**: **MagSafe-compatible** (not MFi-licensed). Use **pre-assembled adhesive 18-magnet ring** from AliExpress (search "Strong Magnetic Ring Wireless Charging Magnet Circle Sticker MagSafe iPhone") — ~NZ$1.10 per ring in qty 10. **No PCB-level magnets** — PCB designer just leaves the back-of-board area behind the ring clear. **Two rings per Device + wall-fixture set**: one stuck to back of Device enclosure, one stuck to wall fixture facing outward. Symmetric ring-to-ring pairing roughly doubles the hold force vs. magnet-to-steel and auto-aligns rotationally. Pull-strength + long-term adhesive (typically 3M VHB) need a one-off bench test before committing.
- ✅ **Qi receiver IC**: **TI BQ51013B** — 5 W Qi Rx, integrated rectifier + LDO, ~5 V output → feeds LiFePO₄ charger directly. Well-trodden part, ~$3 single qty. Pair with a stock flat receiver coil (Würth 760308103xx-series or equivalent), sized to fit inside the magnet ring (~30 mm coil OD inside ~45 mm magnet ring).
- ✅ **NC1000 antenna ↔ magnet clearance**: **≥10 mm minimum** between the antenna trace/element and the nearest magnet. Antenna on a small carrier stub off the top edge of the PCB; magnets + Qi coil + LiFePO₄ on the back face; ground plane between layers. E-paper is RF-transparent, so radiating "through" the display is OK.

## Still to decide before drafting [Schematic placeholder](Schematic_placeholder.md)
1. **PV module design** (separate SKU, downstream of Device) — exact panel choice (amorphous-Si vs mono-Si, size, aesthetic), BQ25570 programming values, connector pinout standardisation, enclosure. Can be designed after the Device PCB is taped out.

## Bench tests to do before committing to production hardware
- **Magnet ring pull test**: confirm AliExpress 18-magnet adhesive ring holds a Device-weight dummy (~250 g) against gravity reliably; verify long-term adhesive on the chosen enclosure material.
- **LFP143060 sample order**: order 5–10 pieces; verify dimensions, integrated protection PCB behavior, and charge curve from the BQ51013B output.

## Ready to draft [Schematic placeholder](Schematic_placeholder.md) now
All architectural decisions are locked. A first sketch / 3D draft of the Device enclosure should accompany schematic drafting so PCB outline + connector positions stay coherent with the enclosure.

## Linked
- [Schematic placeholder](Schematic_placeholder.md) — authoritative schematic (placeholder)
- `schematic-actuator` (internal note) — sibling node, useful as a reference for what "authoritative schematic file" looks like
- `neocortec-project` (internal note) — mesh-level context shared with Actuator and Gateway
- [Sniffer Concept](Sniffer_Concept.md) — future premium air-quality variant (SEN6x + possibly Bosch BMV080), mains-powered, separate product

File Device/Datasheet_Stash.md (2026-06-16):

# Device datasheet stash

Path: `/Users/Shared/Projects/EFW/Device/Docs/`

Layout (mirrors subsystem grouping used in [Brief](Brief.md)):

```
01_MCU/             STM32U585 DS, RM0456, errata, Cortex-M33 PM (PM0264), TrustZone AN, Nucleo UM
02_Display_Touch/   GoodDisplay GDEY042T81-T02, SSD1683 controller, Goodix GT911
03_Sensors/         Sensirion SHT45, SCD41, Infineon BGT60LTR11AIP + radar AppNote
04_Power/           TI BQ51013B (Qi Rx), BQ25570 (PV harvester), LFP143060 spec, Würth Qi coil
05_Mesh/            NC1000 datasheet + AAPI guide (sibling copy of Actuator stash)
06_Misc/            optocouplers, output FETs, glue parts
```

Sibling convention: Actuator KiCad lives at `/Users/Shared/Projects/#Actuator_EFW/KiCad/` (`reference-kicad-locations` (internal note)). Device docs follow the same "Shared/Projects" root but use a non-hashed `EFW/Device/...` tree — single namespace for Device + future Sniffer + shared PV module.

Read this when a Device firmware or schematic session opens and you need register-level or peripheral-protocol detail. Verify the relevant PDF is actually present before quoting page numbers — the stash is populated incrementally.

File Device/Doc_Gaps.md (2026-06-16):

# Device datasheet — gaps & open part choices

Companion to [Datasheet Stash](Datasheet_Stash.md). Two buckets: docs to grab (parts already chosen), and decisions to make (no datasheet possible yet).

**Why:** Aidas wants to pre-load all reference material before HW arrives, mirroring the Actuator prep pattern that paid off heavily. Surfacing genuine misses and TBD parts here so the schematic session doesn't hit "wait, what's the part number?" blockers mid-flow.

**How to apply:** at the start of any Device schematic / firmware bring-up session, scan this list against the live stash and the [Brief](Brief.md) decision log. Tick off as resolved. When Aidas picks one of the TBD parts, move it into [Datasheet Stash](Datasheet_Stash.md) and remove from here.

## Docs to grab (parts already chosen — just missing from initial download list)

### 01_MCU
- **STM32U5 hardware-design application note** — ST's "getting started with hardware development" AN for U5: power tree, decoupling, BOOT0, oscillator selection. Mandatory before schematic.
- **AN2867** — STM32 crystal selection (HSE + LSE design rules, load-cap math). Cross-family canonical ref.
- **Arm ARMv8-M Architecture Reference Manual** — TrustZone / SAU / MPU architecture-level semantics. ST's PM0264 only covers the Cortex-M33 instruction set, not architecture. Source: developer.arm.com.

### 02_Display_Touch
- **GT911 Programming Guide** — separate from the GT911 datasheet. Touch event protocol, I²C register map, config flashing. Both PDFs needed.

### 03_Sensors
- **BGT60LTR11AIP Programming Guide / Radar Fusion GUI / Configurator docs** — chip datasheet alone is not enough to bring the radar up. Infineon's app docs hold the register init sequences and parameter trade-offs.
- **Sensirion SHT45 Interface Description PDF** — separate from main datasheet. Contains I²C state machine and command timing details.
- **Sensirion SCD41 Interface Description PDF** — same pattern: separate from datasheet, contains the single-shot / periodic-measurement state machine.

## Verify before downloading (controller silicon ambiguity)

- **GDEY042T81-T02 e-paper controller — SSD1683 OR UC8276c.** GoodDisplay's 400×300 family ships both depending on revision; the actual silicon on the T02 variant is not pinned down in [Brief](Brief.md). **Action:** read the GDEY042T81-T02 datasheet first to confirm which controller is bonded, then download THAT controller's datasheet. Do not stash both speculatively.

## TBD by part choice — no datasheet until Aidas picks

These are decisions, not download tasks. Each blocks one section of the schematic.

| Part class | Status | Candidates / notes |
|---|---|---|
| LiFePO₄ charger IC (between BQ51013B 5V out and 3.2V LFP cell) | NOT NAMED in brief — brief says BQ51013B "feeds LiFePO₄ charger directly" but doesn't pick one | TI BQ25180 (60–450 mA, tiny), TI BQ25618E, Microchip MCP73123 |
| 3.3 V regulator (from ~3.0–3.6 V LFP rail to MCU/sensors/NC1000) | TBD — class only ("low-Iq LDO") | TI TPS7A02 (25 nA Iq), MAX38640, ADP160 |
| NC1000 antenna part | TBD — chip vs trace not decided | Chip: Johanson 2450AT43A100E. Trace: PCB inverted-F (free but tuning-sensitive) |
| HSE crystal | TBD — frequency + load-cap rating | depends on USB / clocking needs |
| LSE crystal (32.768 kHz for RTC) | TBD — load-cap rating | Abracon ABS07 family typical |
| Low-side NMOS for potential-free outputs | DMG2305UX mentioned in brief as "or similar" — confirm | DMG2305UX or AO3400A |
| Optocoupler for potential-free inputs | LTV-356T / PC817 mentioned as family — confirm specific PN | LTV-356T-A (single-channel) or LTV-846 (quad) |
| Würth Qi receiver coil exact PN | TBD within 760308103xx family | sized to fit inside ~45 mm magnet ring, ≤30 mm OD |
| TVS / ESD protection on screw terminal inputs | NOT in brief — needed for 3–24 V external rail exposure | PESD3V3 family / SMAJ24CA for clamp |
| Sensor-rail load switch (if rails gated for sleep) | NOT in brief — power-budget decision | TPS22910A, SiP32507; only if power profile demands it |

## Closed (already in download plan)
STM32U585 DS, RM0456, ES (errata), Cortex-M33 PM (PM0264), TrustZone AN, Nucleo UM, GDEY042T81-T02 panel DS, SSD1683/UC8276c controller DS (after verify), GT911 DS, SHT45 DS, SCD41 DS, BGT60LTR11AIP DS, BQ51013B DS, BQ25570 DS, LFP143060 spec, NC1000 + AAPI.

## Linked
- [Datasheet Stash](Datasheet_Stash.md) — stash location + folder layout
- [Brief](Brief.md) — authoritative component decisions
- [Schematic placeholder](Schematic_placeholder.md) — schematic file (placeholder until HW exists)
- [Procurement](Procurement.md) — procurement tiers; matches part-choice TBDs above

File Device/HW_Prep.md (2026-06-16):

# Device — Pre-Hardware Prep (while the kit ships)

Kit ordered from Element14 NZ 2026-06-15: NUCLEO-U575ZI-Q + Nordic PPK2 + BGT60LTR11AIP Shield2Go + Sensirion SCD41 SEK + STLINK-V3MINIE. Plus parallel orders to GoodDisplay (touch e-paper) and lithium-lifepo4-battery.com (LFP143060 samples). Estimated arrival: 1–3 weeks depending on customs.

This memo captures the productive work that can happen *before* anything physical is on the bench.

## Where the docs live

```
/Users/Shared/Projects/EFW/Device/Docs/
├── 01_MCU/             STM32U585 datasheet, RM0456, PM0264, ES0499, NUCLEO + STLINK manuals
├── 02_Display_Touch/   GDEY042T81-T02 spec, SSD1683 controller, GT911 touch, TPS65186 PMIC
├── 03_Sensors/         SCD4x datasheet + LP app note, SHT4x, BGT60LTR11AIP datasheet + autonomous AN
├── 04_Power/           BQ51013B + design considerations, BQ25570, LFP143060 spec
├── 05_Mesh/            NC1000 datasheet, NeoCortec AAPI specification
├── 06_Misc/            Nordic PPK2 user guide, LTV-356T opto, DMG2305UX MOSFET
└── DOWNLOADS_TODO.md   list of files still to manually download (ST, Infineon, Goodix, etc.)
```

Re-runnable downloader: `/tmp/efw_device_grab_datasheets.py` (idempotent, skips files already present).

## Suggested reading order

### Priority 1 — read before the kit arrives (~4 hours total)

The four documents whose foundational knowledge unlocks everything else.

1. **STM32U585 datasheet** — chip overview, pin map, package, electrical specs. ~150 pages. **Focus on:** block diagram, pin allocation table, power supply rails, the section on Standby + WKUP-pin selection (critical for NC1000 CTS-wake).
2. **RM0456 reference manual** — peripheral register-level reference. ~2600 pages, *don't read end-to-end*. **Focus on:** TOC, Chapter 6 (clock tree), Chapter 9 (low-power modes — Standby, Stop3, Shutdown), Chapter on EXTI (external interrupts — for the WKUP pin).
3. **UM2861 — NUCLEO-U575ZI-Q user manual** — board pinout, headers (Arduino + Zio + ST morpho), KitProg3 wiring, jumper map.
4. **PM0264 Cortex-M33 programming manual** — read the sleep/wake chapter and the interrupt priority chapter. ~30 pages of relevant material out of ~280 total.

### Priority 2 — read as the kit arrives (~3 hours total)

Peripheral-specific docs for the bring-up work.

5. **GDEY042T81-T02 spec** — display init sequence, refresh-mode commands (full, partial, fast, 4-grayscale). Critical for the display driver.
6. **SSD1683 controller datasheet** — register map for the on-glass controller. Where the SPI bytes actually go.
7. **FT6336U (FocalTech) touch controller datasheet** — I²C protocol (default address 0x38), register map, touch-event format. *Note: confirmed 2026-06-15 that GDEY042T81-T02 uses FT6336U, NOT GT911 as previously assumed. GoodDisplay's product-page Downloads tab supplies STM32 reference code for the FT02/T02 panel + touch — start there rather than writing the driver from scratch.*
8. **SCD4x datasheet** — I²C command set, single-shot vs periodic mode comparison.
9. **SCD4x low-power application note** — exactly the duty-cycling pattern we want for the 5-min cadence.
10. **BGT60LTR11AIP datasheet** — autonomous mode pin descriptions (motion-detect output, direction output, sensitivity potentiometers on the Shield2Go).
11. **BGT60LTR11AIP autonomous mode app note** — the *only* radar mode we plan to use; SPI mode is for tuning only.

### Priority 3 — read when actually implementing that subsystem

12. **TPS65186** — only if going bare-panel route, skip if using DESPI-M02 driver board.
13. **BQ51013B + design considerations** — coil selection + layout when designing Device PCB.
14. **BQ25570** — defer until the PV-module accessory work begins (weeks 4–6).
15. **NC1000 + AAPI spec** — you already know these from the Actuator; quick refresher when wiring the USART driver.

## macOS toolchain setup (can complete without HW)

Verify the development environment works end-to-end against an empty STM32U585 project. Don't need the NUCLEO board for any of this until step 8.

1. Install **STM32CubeIDE** from st.com → free, native macOS, Eclipse-based. *Or* install **VSCode** + the **STM32 for VSCode** extension + **PlatformIO**. PlatformIO is lighter and more modern; CubeIDE is the path-of-least-resistance.
2. Install **STM32CubeMX** (separate app, pin allocation + clock-tree configurator that generates init code). Often bundled with CubeIDE.
3. Install ARM toolchain: `brew install --cask gcc-arm-embedded` (gets `arm-none-eabi-gcc`). CubeIDE bundles its own copy too.
4. Install OpenOCD: `brew install open-ocd` (needed if using VSCode/PlatformIO; CubeIDE bundles its own programmer).
5. Install **nRF Connect for Desktop** from nordicsemi.com → enables the **Power Profiler** app for the PPK2 when it arrives.
6. In CubeMX, create a new project for `STM32U585CIU6` package (QFN-48). Generate code.
7. In CubeIDE / PlatformIO, build the empty project. **Success = toolchain is working.** No flashing yet.
8. (When the NUCLEO board arrives) plug USB-C, run "Program" — confirms ST-LINK is recognised on macOS.

## Firmware scaffolding (skeleton-only, no HW needed)

When ready to commit to the project structure:

1. Create `Energy_Flow_Wall_Code/firmware/device/` (alongside `firmware/actuator/` — if the latter doesn't exist yet, do the restructure as part of this).
2. CubeMX project file with anticipated pin assignments:
   - **SPI1** → e-paper + radar (separate CS lines: PA4 for e-paper, PB6 for radar)
   - **I²C1** → shared SCD41 (0x62) + GT911 touch (0x5D), pull-ups on board
   - **USART2** → NC1000 (TX, RX, CTS) — **CTS must route to a WKUP pin** (PA0 / PC13 / PE6 are the candidates; choose based on rest of pinmux)
   - **GPIO**: BGT60LTR11AIP IRQ, GT911 IRQ + RST, opto-in ×2, MOSFET-out ×2, e-paper BUSY + RST + DC
   - **ADC1** → battery voltage divider
3. CMakeLists.txt or use CubeIDE's Makefile output — either fine.
4. Clone / vendor open-source libraries we'll pull in:
   - **LVGL** (graphics library): https://github.com/lvgl/lvgl
   - **GxEPD2** (e-paper, has STM32 ports): https://github.com/ZinggJM/GxEPD2 — adapter pattern, easy to lift the SSD1683 backend.
   - **Sensirion SCD4x driver** (official C library): https://github.com/Sensirion/embedded-i2c-scd4x
   - **Infineon RDK-TR11 SDK** for the radar: search "BGT60LTR11AIP driver github" — Infineon publishes example code.
5. Draft a top-level state machine sketch: idle/sleep → wake-on-touch / wake-on-CTS / wake-on-radar / wake-on-RTC-tick → service event → return to sleep.
6. Sketch the power-state diagram (Standby / Stop3 / Sleep / Run) and which wake-sources trigger which.

## Three things to do today (no HW needed)

If you want concrete tasks for an hour or two right now:

- [ ] Click through `DOWNLOADS_TODO.md` and grab the 6 ST PDFs into `01_MCU/`. They're the highest-value reading material and the easiest manual download.
- [ ] Install STM32CubeIDE (or VSCode + PlatformIO) and confirm an empty STM32U585 project compiles.
- [ ] Open the STM32U585 datasheet to the WKUP-pin section and decide which pin NC1000 CTS will route to. Note the choice for the PCB design.

## Linked

- [Brief](Brief.md) — the architectural locks this is preparing to implement
- [Procurement](Procurement.md) — what's being shipped that this prep is for
- [Schematic placeholder](Schematic_placeholder.md) — the file this prep eventually produces (PSoC reference replaced by STM32U585)
- `reference-psoc-flash-workflow` (internal note) — Actuator's flash workflow; the STM32 equivalent (just CubeIDE's "Program" button on macOS, no VM dance) is much simpler

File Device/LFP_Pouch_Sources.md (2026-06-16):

# LFP Pouch Cell — Sourcing Reference (2026-06-14)

For Device project — Aidas wanted ANY verifiable producer making LFP pouch cells; the cylindrical-only market is well-trodden but pouch LFP is a niche. Three real options confirmed below.

## Primary — LFP143060 (1800 mAh, 14 × 30 × 60 mm)

- **Vendor**: lithium-lifepo4-battery.com — claims 10+ years as LFP manufacturer (China).
- **URL**: https://www.lithium-lifepo4-battery.com/lifepo4-battery-lfp143060-1800mah-3-2v/
- **PN encodes geometry**: `LFP` (chemistry) + `14` (thickness mm) + `30` (width mm) + `60` (length mm).
- **Specs**: 1800 mAh, 3.2 V nominal, 5.76 Wh, integrated protection PCB, >2000 cycles claimed.
- **Sample MOQ**: 5–10 pieces.
- **Sample lead time**: 3–5 days.
- **Production scale**: vendor claims 100k+ unit capacity.
- **What to verify on sample**: exact dimensions, weight, protection-PCB cutoff thresholds (overcharge / overdischarge / overcurrent), actual capacity at 0.2C discharge, internal resistance, behaviour from BQ51013B (MagSafe Rx) charge input.

## Backup #1 — Grepow

- **URL**: https://www.grepow.com/lifepo4-battery.html (LFP product family)
- **Notes**: Well-established Shenzhen battery manufacturer. Multiple LFP pouch lines including high-discharge variants (20C, 25C, 40C — overkill for our use). Sample-friendly, MOQ typically ~100 for stock sizes, ~500 for custom. Quote turnaround usually a few days via their sales contact form.
- **When to use**: if `lithium-lifepo4-battery.com` is unreachable or LFP143060 dims don't suit final enclosure.
- **Encyclopedia article on LFP pouches** (useful background): https://www.grepow.com/lfp-battery-encyclopedia/what-is-soft-pack-lithium-iron-phosphate-lifepo4-battery.html

## Backup #2 — Misen Power

- **URL**: https://www.misenpower.com/LiFePO4-Pouch-Cell-pl49090897.html
- **Notes**: Explicit "LiFePO4 Pouch Cell" product page. Less detail than Grepow but a third independent source confirming this market segment exists.

## Why pouch was harder to find than expected

LFP is a safer chemistry but lower energy density than NMC/LCO (~330 vs ~600 Wh/L). Most LFP capacity is sold as cylindrical (18650 LFP, 26650 LFP, 32650 LFP) because the rigid case suits the chemistry well. Pouch LFP exists but is a niche — used where slim form factor matters more than peak power density. Mainstream LFP makers (CATL, BYD, EVE) focus on prismatic/cylindrical; pouch is left to specialist makers and customs.

For Device's wall-mount form factor, pouch is correct (14 mm thick vs. 26 mm for 26650 = ~12 mm thinner Device).

## Linked

- [Brief](Brief.md) — the project this sourcing serves
- [Sniffer Concept](Sniffer_Concept.md) — future product, mains-powered, will NOT need LFP pouch

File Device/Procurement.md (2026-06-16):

# Device — Development Procurement List (2026-06-14)

Prepared to share with Poul to budget hardware needed before Device firmware + PCB work starts. Prices are USD, rounded, from major distributors (Digi-Key / Mouser) unless noted. Local taxes / shipping / NZD conversion not included. Exact prices to verify at point-of-purchase.

## Tier 1 — Essential (can't make progress without these)

| Item | Part / Source | ~Price USD | Purpose |
|---|---|---|---|
| **STM32U5 Nucleo Prototyping Board** | NUCLEO-U575ZI-Q (STMicroelectronics) — Digi-Key / Mouser | ~$33 | MCU bring-up, firmware development. Has on-board ST-LINK V3 programmer/debugger, Arduino + Zio + ST morpho headers, USB-C for power+programming. Native macOS workflow via STM32CubeIDE *or* VSCode + STM32-PlatformIO. **(MCU switched from PSoC6 to STM32U5 on 2026-06-15 — Aidas walked away from Infineon's PSoC tooling trajectory; STM32U5 also gives us 2 MB flash in a hand-solderable QFN-48 for the production board.)** |
| **Nordic Power Profiler Kit II** | PPK2 (Nordic Semiconductor) — Digi-Key / Mouser | ~$95 | **Settles the NC1000 1/sec ALT-mode wake question once and for all.** Also instruments every sleep current measurement on Device, sensor duty cycles, SCD41 single-shot energy, etc. Critical for proving the 6–12 month MagSafe interval before shipping. |
| **BGT60LTR11AIP Radar Shield2Go (full eval)** | **S2GORADARBGT60LTR11TOBO1** (Infineon) — RS Online / Farnell / Mouser | **~$50** (~$76 AUD ex-GST at RS Australia) | Full Shield2Go eval board. Has **mode-select switches** (autonomous vs SPI) + **threshold potentiometers** for tuning the four QS signals mechanically without firmware. Both modes directly useful for Device development. Far cheaper than the DEMO-BGT60LTR11AIP ($171). Don't confuse with the simpler SHIELDBGT60LTR11AIPTOBO1 ($40, discontinued at Digi-Key, autonomous-only-ish 4-pin module). |
| **GoodDisplay GDEY042T81-T02** (touch e-paper, 4.2" 400×300) | GoodDisplay direct or [buyepaper.com](https://buyepaper.com) | ~$35–50 | The display. Confirmed with touch overlay so this also covers GT911 evaluation. Order at least 2 (one for the bench, one as spare). |
| **DESPI-M02 Mini Driver Board** (or similar) | GoodDisplay direct | ~$15 | The TPS65186 HV driver + connector breakout. Plugs into the panel's FPC, exposes SPI to the STM32U5. Only needed if buying the bare panel — confirm whether the -T02 kit ships with one. |
| **Sensirion SCD41 Evaluation Kit** | SCD4x SEK — Digi-Key / Sensirion | ~$45–55 | CO₂ sensor on a breakout with SHT45 onboard too. Lets you validate single-shot energy + cadence + accuracy at room. |
| **Sensirion SHT45 breakout** | Adafruit 5665 or similar | ~$8 (skip if you have spare from Actuator pile) | T/H sensor on breakout. Probably already covered by the SCD41 SEK above. |
| **MagSafe magnet rings** | [AliExpress 10× set](https://www.aliexpress.com/item/1005007351344807.html) | ~NZ$11 (~$7) | Aidas already found this — 18-magnet pre-assembled rings. Two per Device-and-fixture set. |
| **LFP143060 LiFePO₄ pouch samples** | [lithium-lifepo4-battery.com](https://www.lithium-lifepo4-battery.com/lifepo4-battery-lfp143060-1800mah-3-2v/) — sample MOQ 5–10 | ~$50 + shipping | Battery cell for the Device. 1800 mAh, 14×30×60 mm. Used as final battery and as charging-rig load. |

**Tier 1 subtotal: ~$290–330 USD** + shipping (saved ~$12 vs the original PSoC6 kit budget by switching to the NUCLEO-U575ZI-Q).

## Tier 2 — Important (need before PCB tape-out)

| Item | Part / Source | ~Price USD | Purpose |
|---|---|---|---|
| **TI BQ51013B Qi Receiver EVM** | BQ51013BEVM-764 — Digi-Key / Mouser | ~$70 | Wireless charging Rx evaluation. Validate charging from a MagSafe pad onto LFP143060, measure efficiency. |
| **TI BQ25570 Solar Harvester EVM** | BQ25570EVM-206 — Digi-Key / Mouser | ~$50 | Solar harvester eval for the PV-module accessory SKU. |
| **MagSafe / Qi charging pad** | Anker MagGo, generic MagSafe puck, or Apple MagSafe Duo | ~$25–40 | The source side of the wireless charging — needed to bench-test BQ51013B + magnet ring + LFP charging chain. |
| **Small amorphous-Si solar panel** | Powerfilm SP3-37 (~$15) or 50×30 mm mono-Si sample | ~$15–25 | For the PV-module BQ25570 testing. |
| **Extra NC1000 modules** | NeoCortec NC1000C, qty 2–3 | ~$30 each = ~$90 | One to act as Device mesh node, one as spare. Possibly already covered by Aidas's existing NC1000 stock from Actuator work — confirm. |

**Tier 2 subtotal: ~$250–325 USD.**

## Tier 3 — Nice to have / risk reduction

| Item | Part / Source | ~Price USD | Purpose |
|---|---|---|---|
| **Saleae Logic 8** (or cheap clone $20) | Saleae / SparkFun | ~$400 (Saleae) or ~$20 (clone) | Debugging SPI / I²C / UART when something doesn't talk. Aidas may already own one. |
| **ST-LINK V3 MINI standalone programmer** | STLINK-V3MINIE — Digi-Key / Mouser | ~$11 | Only needed once moving from the NUCLEO board to a custom Device PCB. The on-board ST-LINK V3 on the NUCLEO covers Tier 1 work fine. Skip the $45 V3 SET — its extras (JTAG, SWO trace, USB-to-I²C bridge) aren't relevant for STM32U5 + USART debug print; if SWO trace ever becomes worth it, it's a $34 incremental purchase later. |
| **Pmod breakouts / jumper wires / 0.5 mm FPC adapters** | Adafruit / SparkFun assortment | ~$30 | The boring stuff that makes connecting heterogeneous parts possible on a bench. |
| **Second GoodDisplay panel — base GDEY042T81 (no touch)** | GoodDisplay | ~$25 | Optional A/B testing: how much does the PET overlay degrade contrast / refresh feel vs. bare e-paper? |

**Tier 3 subtotal: ~$90–490 USD** (huge range because of Saleae).

## Total

| Scenario | USD | NZD (~×1.65) |
|---|---|---|
| Tier 1 only (start firmware) | ~$310 | ~$510 |
| Tiers 1 + 2 (through PCB design) | ~$565 | ~$930 |
| Tiers 1 + 2 + 3 (everything incl. Saleae) | ~$990–1090 | ~$1680–1780 |

Realistic ask for Poul to cover the *productive* hardware (everything Aidas can't sensibly proceed without): **Tiers 1 + 2 ≈ ~$565 USD / ~$930 NZD**. Tier 3 can be added piecemeal as the project progresses.

## Things Aidas already has (no need to budget)

Verify before ordering — these are believed to be on-hand from Actuator work:
- Oscilloscope
- Bench power supply
- Soldering iron + hot-air rework (for hand-rework of QFNs)
- Multimeter
- Some NC1000 modules
- USB serial adapters
- LiPo / Li-Ion cells (not LFP though)

## What's deliberately NOT on this list

- **Custom Device PCB fabrication** — deferred until after firmware bring-up validates the architecture on the proto kit. JLCPCB / PCBWay assembly run will be separate cost (~$200–500 for a small batch of 5 boards including BGA assembly).
- **PV module PCB** — separate downstream SKU, not blocking.
- **Production enclosure (3D-printed or injection-molded)** — Aidas already prints, FDM cost is negligible.
- **NeoTools NC1000 development kit** — Aidas already has access via existing Actuator workflow.

## Update history

- 2026-06-14: Initial list, written after Device sensor / power / display / mesh / mechanical decisions locked.

## Linked
- [Brief](Brief.md) — what each kit supports
- [LFP Pouch Sources](LFP_Pouch_Sources.md) — battery sourcing detail
- [Sniffer Concept](Sniffer_Concept.md) — separate future product, no kits here yet

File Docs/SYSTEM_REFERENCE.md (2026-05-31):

# Energy Flow Wall — System Reference

## Mesh & Communication
- NC1000 (mesh radio) is hardwired to PSoC5 with 3 wires: CTS, RX, TX. No button.
- Commands sent from Node-RED via TCP, running on RP5. RP5 is hardwired to a Gateway NC1000.
- NC1000 sends binary AAPI packets (not plain text). Start bytes: 0x52 or 0x54.
- Mesh has 2 modes:
  - **Normal**: all NC1000 nodes collect T/H from SHT45 sensors, send to NeoGateway on RP5
  - **ALT**: triggered by Node-RED when conditions met (e.g. temperature threshold); NC1000 stops T/H and switches to UART mode so any command can be sent to any mesh node

## Device Types in Mesh
- **Gateway**: RP5 + NC1000, runs NeoGateway TCP server, Node-RED, InfluxDB, Grafana
- **Actuator**: PSoC5 + NC1000 + DRV8411A + 2 motors + 2 encoders + SHT45. Controls flaps. NC1000 mesh node ID: 0x55 (decimal 85).
- **Device**: NC1000-only nodes collecting T/H data. Node IDs: 0x33, 0x44.

## Actuator Hardware (Main PCB — KiCad: Hardware/KiCad/Main_PCB_Based_on_8411A)

### ICs / Active components
- **U1 — PSoC5**: CY8C5888LTQ-LP097 (ARM Cortex-M3, 80MHz, 256KB flash, 68-QFN)
- **U2 — Motor driver**: DRV8411ARTER — single chip, dual H-bridge, drives both motors independently
  - AIPROPI / BIPROPI: current sense outputs (ratio 1:2000) → R11/R12 = 1K5Ω each → PSoC ADC
  - VREF: driven by PSoC VDAC8 (software-controlled OCP threshold)
  - nFAULT: active-low fault output → PSoC interrupt
  - AIN1/AIN2, BIN1/BIN2: PWM inputs from PSoC (PWM_1, PWM_2 components)
- **U3 — T/H sensor**: SHT45-AD1F-R2 (on Actuator board — reports its own T/H to mesh)
- **U4 — Motor supply**: TPS63020QDSJRQ1 buck-boost converter, Vin 1.8–5.5V → Vout **5.0V** (R7=1.8M, R10=200K)
  - L1 = XAL4020-152MEC 1.5µH inductor (Coilcraft, on the same supply)
  - Enabled only during motor motion (M_Power pin) to save battery
- **U5 — System supply**: AP7354-33W5-7 LDO → 3.3V for logic (PSoC, NC1000, SHT45, encoders)
- **U6 — Mesh radio**: NC1000C
- **Q1 — Polarity protection**: BUK6Y33-60PX PMOS FET (60V, 30A)

### Passive / discrete
- **D1**: Blue status LED (LTST-C170TBKT)
- **R7=1.8MΩ, R10=200KΩ**: TPS63020 output voltage setting → 5.0V
- **R11, R12=1K5Ω**: AIPROPI/BIPROPI current sense load resistors → PSoC ADC

### Connectors
- **J3**: BM03B-PASS-1-TFT — 3-pin JST, fan output (Fan_PWM → P2[3])
- **J4, J5**: FM20C06VBNN — 6-pin encoder connectors (A, B, power, GND per motor)
- **J1, J2, J6**: ECV3-06 Tag-Connect — programming/debug headers (PSoC + NC1000)
- **JP1**: SolderJumper_3_Bridged12 — motor power source selection
  - **1–2 bridged** (default): battery powered → routes supply through U4 (TPS63020 buck-boost) for stable 5V motor rail
  - **2–3 bridged**: regulated supply (e.g. USB 5V 2A) → bypasses U4 entirely, connects supply directly to motor rail
  - DNP in this config: U4, L1, R7, R10 (converter + frequency-setting components) and all decoupling caps on U4 Vin/Vout rails: C22, C23, C24 (22µF bulk), C25, C26, C29 (0.1µF bypass), C30, C31 (10µF bulk)

## Motors
- **Pololu #3078**: 250:1 (actual 248.98:1) Micro Metal Gearmotor HPCB 6V
  - Rated voltage: 6V (run at 5V from TPS63020 — ~17% derated, acceptable)
  - No-load: 130 RPM, 150 mA at 6V
  - Stall: 3.2 kg·cm torque, **1.5A** current (DRV8411A rated 1.92A peak — OK)
- 2 motors, **mechanically independent** (M1 and M2 drive separate flaps)
- Expected flap travel: ~180° (TBC by homing)

## Encoders (Encoder PCB V2.0 — KiCad: /Users/Shared/Projects/#Actuator_EFW/KiCad/Pololu_Encoder_V2/Encoder.kicad_pro_v2)
- Custom PCB, based on Pololu magnetic encoder design for Micro Metal Gearmotors
- **12 CPR** on motor shaft (Hall effect, sensor: TLE4946-2K, Infineon, SOT-23)
- Quadrature A+B only (no index). PSoC5 uses hardware QuadDec_3 / QuadDec_4 components.
- Effective resolution: 12 × 4 × 248.98 ≈ **11,951 counts/output shaft revolution**
- Expected counts for full travel (~90° at output shaft): **~3000 counts** (confirmed experimentally)
- Encoder power controlled by Hall_Pwr pin (off when not needed)
- **TO BE DONE (next PCB revision)**: Power encoders from TPS63020 5V rail (already auto-switched by M_Power hardware OR gate — free power control, no extra FET needed). Add 8× voltage divider resistors on main PCB (2 per signal × 4 signals: M1_A, M1_B, M2_A, M2_B) to bring 5V open-drain outputs down to ~3.3V for PSoC. Divider values: R_top=5.6K + R_bottom=10K → 3.2V at PSoC pin. Encoder PCB unchanged (R1/R2 pull-ups to Vcc stay). Result: encoders off during sleep at zero extra BOM cost vs a FET.

## PSoC5 Firmware — Key PSoC Creator Components
- QuadDec_3, QuadDec_4: hardware quadrature decoders for M1/M2 (2 QuadDecs, not 4)
  - 16-bit signed counters. API: `QuadDec_3_GetCounter()` → int16, `QuadDec_3_SetCounter(int16)`
  - Full output shaft revolution ≈ 6000 counts (2× decoding). Max flap travel ≈ 3000 counts.
  - Counter trick for precise position stop: SetCounter(32767−steps) for CCW → overflow ISR fires
    after exactly `steps` counts; SetCounter(steps−32768) for CW → underflow ISR fires.
  - isr_QuadDec3 / isr_QuadDec4: user ISR components; use `QuadDec_3_GetEvents()` in handler
    (flags: QuadDec_3_COUNTER_OVERFLOW, QuadDec_3_COUNTER_UNDERFLOW)
- PWM_1, PWM_2: motor speed control (0–255, 8-bit). API: `PWM_1_WriteCompare(uint8)`
- PWM_3: fan speed control. Output routed to Fan_PWM pin.
- VDAC8_1, VDAC8_2: OCP threshold per motor (0–255). VDAC8_3: VREF for DRV8411A
- Comp_1, Comp_2: OCP comparators. Outputs → M1_ovcr / M2_ovcr nets
- Opamp_1, Opamp_2: AIPROPI / BIPROPI signal conditioning
- Em_EEPROM: emulated EEPROM. Init: `Em_EEPROM_Init((uint32)storageArray)`.
  Read/Write: `Cy_Em_EEPROM_Read/Write(addr, data, size, &Em_EEPROM_context)`
- Hall_Pwr: pin exists in firmware but not connected in current HW — pin unused
  - **PCB TODO (next revision)**: encoder power will be switched via TPS63020 5V rail (see Encoders section) — Hall_Pwr pin may be repurposed or removed
- Fan_PWM: fan output pin (driven by PWM_3)

## PSoC5 Hardware Motor Control Architecture (from schematic)
Source: PSoC_schematics_full_w_8411A_w_interrupt_new.pdf

**M1_Go / M2_Go SR flip-flops (hardware state machine):**
- Pulse M1_Go pin HIGH → SRFF sets (Q=1) → de-asserts PWM_1 kill → motor runs
- QuadDec_3 overflow/underflow → resets M1_Go SRFF (Q=0) → asserts kill → motor stops
- M1_ovcr (OC latch) → also resets M1_Go SRFF → motor stops on overcurrent
- nFAULT (inverted) → resets both M1_Go and M2_Go SRFFs → emergency stop both

**M_Power (TPS63020 enable) is hardware-driven:**
- OR(M1_Go_SRFF_Q, M2_Go_SRFF_Q) → M_Power pin — automatic, no firmware control needed

**Status register (Status_Read() → uint8):**
| Bit | Mask | Meaning |
|-----|---|---|
| 0 | 0x01 | M1 stopped (HIGH) / running (LOW) = !M1_Go_SRFF_Q |
| 1 | 0x02 | M2 stopped (HIGH) / running (LOW) = !M2_Go_SRFF_Q |
| 2 | 0x04 | M1 OC latched (M1_ovcr SRFF Q) |
| 3 | 0x08 | M2 OC latched (M2_ovcr SRFF Q) |
| 4 | 0x10 | nFAULT active (HIGH = DRV8411A fault) |

- isr_Status fires on any status bit change → use for interrupt-driven move completion
- RST_ovcr pin resets M1_ovcr + M2_ovcr SRFFs (clears OC latches)

**Motor start sequence:**
1. `ResetOCP()` — clear OC latches (RST_ovcr pulse)
2. `VDAC8_1_SetValue(startup_thresh)` — apply startup OCP override
3. `M1_Dir_Write(dir)` + `PWM_1_WriteCompare(pwm)` — set direction and speed
4. `M1_Go_Write(1); CyDelayUs(10); M1_Go_Write(0)` — pulse to set SRFF, motor starts
5. `CyDelay(d0_ms); VDAC8_1_SetValue(run_thresh)` — drop to running threshold

## Firmware Versioning
- Format: main_vX.Y.Z — continue from v1.3.103 (sleep working) / v1.3.104 (sleep disabled debug)
- Next version: v1.3.105
- Files in /Users/aidas/Desktop/

## PSoC5 Firmware — Critical Notes
- CyPmSaveClocks() / CyPmRestoreClocks() are critical for hibernate
- CTS line is shared between UART and wake interrupt
- Timeout protection needed for spurious wakes (WAKE_TIMEOUT = 200 × 10ms = 2s)
- Race condition prevention with shouldSleep flag (set BEFORE processing, checked FIRST in loop)

## Actuator Command Set (AAPI Port 4, via NC1000 mesh in ALT mode)
| Command | Description | TBD |
|---|---|-----|
| M1 \<counts\> | Move motor 1 to absolute encoder position | - |
| M2 \<counts\> | Move motor 2 to absolute encoder position | - |
| S1 \<pwm\> | Set motor 1 speed (PWM duty cycle) | format TBD |
| S2 \<pwm\> | Set motor 2 speed (PWM duty cycle) | format TBD |
| T1 \<val\> | Set motor 1 running OCP threshold | units TBD |
| T2 \<val\> | Set motor 2 running OCP threshold | units TBD |
| T01 \<val\> | Motor 1 startup OCP threshold override (higher, to overcome stiction) | - |
| T02 \<val\> | Motor 2 startup OCP threshold override | - |
| D01 \<ms\> | Duration of motor 1 startup threshold override | - |
| D02 \<ms\> | Duration of motor 2 startup threshold override | - |
| H1 | Home motor 1 on demand | - |
| H2 | Home motor 2 on demand | - |

## Homing Sequence (per motor, M1 then M2 — sequential to avoid current spike)
1. Enable TPS63020 (M_Power pin)
2. Start motor at low speed (PWM=50/255) toward home1 direction
3. Monitor AIPROPI/BIPROPI for overcurrent → motor stalled → record as home1, zero encoder
4. Apply startup threshold override (T0x) for D0x ms at start of each move to overcome stiction
5. Reverse, run to opposite end at same speed, stall → record as home2
6. Compute travel = abs(home2 - home1) in encoder counts. Expected: ~3000 counts
7. If travel outside 3000 ± 20 counts:
   - Too few counts → insufficient torque: increase PWM by 5/255, retry from step 2
   - Max 3 retries; if still failing → send Alert to Node-RED, stop motors, await H1/H2
   - Way out of range (stuck) → same: Alert + stop
8. Save home1, home2, working PWM, thresholds to Em_EEPROM
9. Homing runs on every power cycle

### Homing parameters (confirmed)
- Starting PWM: 50/255
- PWM increment per retry: 5/255
- Max retries: 3, then Alert
- Valid travel range: 3000 ± 20 counts
- All values (PWM, thresholds) are 0–255 (8-bit, matching PWM_M1/M2 and VDAC8)

## Node-RED / RP5
- SSH: ssh rp5.local (user: aidas)
- Node-RED flows: ~/.node-red/flows.json, port 1880
- Deploy: curl -X POST http://localhost:1880/flows -H 'Content-Type: application/json' -H 'Node-RED-Deployment-Type: full' -d @~/.node-red/flows.json
- InfluxDB: db=neogw, measurement=htu21d, fields: tempC, rh, nodeIdHex (as field not tag)
- Grafana dashboard: /Users/aidas/Desktop/NeoCortec-dashboard-fixed.json

## Sensor Formulas (Node-RED function d110437aa9daf440)
- 0x33, 0x44 (HTU21D): T = -46.85 + 175.72 × raw/65536, RH = -6 + 125 × raw/65536; mask raw & 0xFFFC
- 0x55 (SHT45): T = -45.0 + 175.0 × raw/65535, RH = -6.0 + 125.0 × raw/65535; mask raw & 0xFFFC

## GitHub
- Repo: https://github.com/ajanulis/Energy_Flow_Wall.git
- Contains: KiCad hardware designs (Main PCB, Encoder PCB V2.0, Gateway PCB, End PCB)
- Source code in separate private repo

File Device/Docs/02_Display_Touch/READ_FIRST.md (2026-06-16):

# Display + Touch — reading priority

**Touch controller is confirmed FT6336U (FocalTech), NOT GT911 (Goodix).**
Verified 2026-06-15 from good-display.com/product/473.html → Downloads tab.

## Files in priority order

1. **`GDEY042T81-T02.pdf`** — panel spec from GoodDisplay. Init sequence + refresh modes.
2. **`FT6336U-DataSheet-V1.0.pdf`** — touch controller. I²C address 0x38, register map, touch-event format.
3. **`TPS65186_datasheet.pdf`** — HV PMIC for e-paper bias rails. Only need to read if going bare-panel route; if using the DESPI-M02 driver board, this is internal to that board.
4. **`GDEY42T81-T02-drawing.pdf`** — mechanical drawing. Useful when designing the enclosure cutout.
5. **`Catalog-New.pdf`** — GoodDisplay general catalogue. Reference only.

## Sample code archives — the gold mine

Three RARs were extracted in-place. **The one to mine first:**

### `S-GDEY042T81-FP-Touch20230405/` — the complete reference firmware

Targets STM32F103 (different family from our STM32U585, but chip-side code is 100% portable).
Key files:

- `HARDWARE/EPD/Display_EPD_W21.c/h` — e-paper SSD1683 driver: init sequence, refresh modes, framebuffer push.
- `HARDWARE/EPD/Display_EPD_W21_spi.c/h` — bare-metal STM32F1 SPI. **REPLACE** with STM32U5 HAL SPI when porting.
- `HARDWARE/FT6336/FT6336.c/h` — FT6336 touch driver: I²C reads, touch-event decoding, IRQ handling.
- `HARDWARE/I2C/i2c.c/h` — bare-metal STM32F1 I²C. **REPLACE** with STM32U5 HAL I²C when porting.
- `HARDWARE/Fonts/` — 7 bitmap fonts (8/12/16/20/24 px Latin, 12/24 px Chinese). **LIFT AS-IS.**
- `HARDWARE/GUI/GUI_Paint.c/h` — drawing primitives (lines, rectangles, text). Pure framebuffer code. **LIFT AS-IS.**
- `USER/main.c` — demo application; shows the init → loop → handle touch → refresh pattern.

### `FT6336_4.2DEMO20200914/` — older, FT6336-only

Subset of the above. Skip — the middle archive has everything.

### `T042T81&EPD_ESP32-20230523/` — ESP32 / Arduino

Useful as a reference for behaviour comparison only — Arduino style, not directly portable to STM32.

## Porting strategy when firmware bring-up starts

1. Create a fresh STM32U5 firmware project in CubeMX (pin mux, clock tree, HAL init).
2. **Lift fonts + GUI_Paint directly** into `firmware/device/lib/gui/`.
3. **Lift the e-paper init sequences** from `Display_EPD_W21.c`. Wrap them in your STM32U5 HAL SPI calls — the bytes sent to the panel are identical regardless of host MCU.
4. **Lift the FT6336 register reads** from `FT6336.c`. Wrap in HAL I²C calls.
5. **Replace** bare-metal F103 peripheral code with HAL equivalents — shape stays the same.
6. **Discard** the `STM32F10x_FWLib/` StdPeriph library — superseded by CubeMX HAL on U5.
7. **Recreate** the build setup as STM32CubeIDE or VSCode/PlatformIO project; Keil µVision files are ignored.

This saves ~1–2 weeks of firmware bring-up. The init sequences and waveform tables alone would otherwise be a multi-day reverse-engineering exercise.

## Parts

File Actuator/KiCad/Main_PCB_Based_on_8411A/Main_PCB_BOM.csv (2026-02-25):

Comment | Designator | Footprint | JLCPCB Part #（optional）
 | J1, J2 | FM20C06VBNN

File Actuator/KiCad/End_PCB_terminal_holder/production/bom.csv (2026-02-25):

Designator | Footprint | Quantity | Value | LCSC Part #
J1 | 2843915 | 1 | Screw_Terminal_01x05
J2 | 3pin_flat | 1 | ~

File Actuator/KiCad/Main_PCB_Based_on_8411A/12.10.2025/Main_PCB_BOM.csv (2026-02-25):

Id | Designator | Footprint | Quantity | Designation | Supplier and ref
1 | U5 | NC1000c | 1 | NC1000C
2 | U3 | HTSSOP-16-1EP_4.4x5mm_P0.65mm_EP3.4x5mm_Mask2.46x2.31mm_ThermalVias | 1 | DRV8833PWP
3 | U1 | QFN40P800X800X100-69N | 1 | CY8C5888LTQ-LP097
4 | U4 | Sensirion_DFN-4_1.5x1.5mm_P0.8mm_SHT4x_NoCentralPad | 1 | SHT4x
5 | J2,J1 | FM20C06VBNN | 2 | FM20C06VBNN

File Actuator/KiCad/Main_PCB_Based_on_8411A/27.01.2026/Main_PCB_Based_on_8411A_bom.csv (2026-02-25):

Comment | Designator | Footprint | JLCPCB Part # | MFR.Part # | Qty | DNP | Exclude from BOM | Exclude from Board | Datasheet
0.1uF | C1,C2,C3,C5,C7,C9,C10,C12,C13,C14,C17,C18,C20,C21,C25,C26,C28,C29,C33 | Capacitor_SMD:C_0402_1005Metric | C77014 | GRM155R71E104KE14D | 19 |  |  |  | ~
10uF 16V | C4,C27 | Capacitor_SMD:C_0805_2012Metric | C408142 | GRM21BR71C106KE51L | 2 |  |  |  | ~
1uF | C6,C8,C11,C16,C19 | Capacitor_SMD:C_0402_1005Metric | C528974 | GRM155Z71A105KE01D | 5 |  |  |  | ~
22uF | C15,C22,C23,C24,C32 | Capacitor_SMD:C_0603_1608Metric | C77042 | GRM188R60J226MEA0D | 5 |  |  |  | ~
10uF | C30,C31 | Capacitor_SMD:C_0805_2012Metric | C408142 | GRM21BR71C106KE51L | 2 |  |  |  | ~
BLUE | D1 | LED_SMD:LED_0805_2012Metric | C98222 | LTST-C170TBKT | 1 |  |  |  | ~
ECV3-06 | J1,J2,J6 | Tag-Connect-ECV3-Footprints:ECV3-06 |  |  | 3 |  | Excluded from BOM
BM03B-PASS-1-TFT | J3 | BM03B_PASS_1_TFT:JST_BM03B-PASS-1-TFT | C485351 | BM03B-PASS-1-TFT(LF)(SN) | 1
FM20C06VBNN | J4,J5 | FM20C06VBNN:FM20C06VBNN |  |  | 2 |  |  |  | FM20C06VBNN
SolderJumper_3_Bridged12 | JP1 | Jumper:SolderJumper-3_P1.3mm_Bridged12_RoundedPad1.0x1.5mm |  |  | 1 |  | Excluded from BOM |  | ~
1.5uH | L1 | Inductor_SMD:L_Coilcraft_XxL4020 | C18547833 | XAL4020-152MEC | 1 |  |  |  | ~
BUK6Y33-60PX | Q1 | BUK6Y33-60P:LFPAK_SOT669_NEX |  |  | 1 |  |  |  | BUK6Y33-60PX
4K7 | R1 | Resistor_SMD:R_0402_1005Metric | C5455562 | AC0402FR-7W4K7L | 1 |  |  |  | ~
K82 | R2 | Resistor_SMD:R_0402_1005Metric | C25135 | 0402WGF8200TCE | 1 |  |  |  | ~
7K5 | R3 | Resistor_SMD:R_0402_1005Metric | C6117685 | AC0402FR-7W7K5L | 1 |  |  |  | ~
10K | R4,R5,R8,R9 | Resistor_SMD:R_0402_1005Metric | C25744 | 0402WGF1002TCE | 4 |  |  |  | ~
7K5 | R6 | Resistor_SMD:R_0402_1005Metric | C6117679 | AC0402FR-7W3K9L | 1 |  |  |  | ~
1M8 | R7 | Resistor_SMD:R_0402_1005Metric | C185447 | RC0402FR-071M8L | 1 |  |  |  | ~
200K | R10 | Resistor_SMD:R_0402_1005Metric | C25764 | 0402WGF2003TCE | 1 |  |  |  | ~
1K5 | R11,R12 | Resistor_SMD:R_0402_1005Metric | C5575287 | AC0402FR-7W1K5L | 2 |  |  |  | ~
CY8C5888LTQ-LP097 | U1 | CY8C5888LTQ-LP097:QFN40P800X800X100-69N |  |  | 1
DRV8411A | U2 | DRV8411ARTER:WQFN16_RTE_TEX | C18816315 | DRV8411ARTER | 1 |  |  |  | https://www.ti.com/lit/gpn/drv8411a
SHT45 | U3 | SHT45-AD1F-R2:SHT45_C_cutout_clean_new | C5360602 | SHT45-AD1F-R2 | 1 |  |  |  | https://sensirion.com/media/documents/33FD6951/624C4357/Datasheet_SHT4x.pdf
TPS63020-Q1 | U4 | TPS63020QDSJRQ1:TPS63020QDSJRQ1 | C2876554 | TPS63020QDSJRQ1 | 1 |  |  |  | https://www.ti.com/lit/gpn/tps63020-q1
AP7354-33W5-7 | U5 | AP7354:SOT25_AP7354_DIO | C460386 | AP7354-33W5-7 | 1 |  |  |  | AP7354-33W5-7
NC1000C | U6 | NeoCortec:NC1000c |  |  | 1

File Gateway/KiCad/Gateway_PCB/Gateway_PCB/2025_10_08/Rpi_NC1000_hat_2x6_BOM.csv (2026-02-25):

Id | Designator | Footprint | Quantity | Designation | Supplier and ref
1 | U1 | NC1000 | 1 | NC1000C-8
2 | J1 | ECV3-06 | 1 | Conn_01x06_Pin
3 | C1 | C_0603_1608Metric | 1 | 3u3 16V
4 | R1 | R_0603_1608Metric | 1 | 1k
5 | J2 | PinHeader_2x06_P2.54mm_Vertical | 1 | Conn_02x06_Odd_Even
6 | D1 | LED_0603_1608Metric | 1 | Led_green
7 | R2 | R_0603_1608Metric | 1 | 10k

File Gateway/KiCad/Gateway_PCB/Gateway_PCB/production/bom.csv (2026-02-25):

Designator | Footprint | Quantity | Value | LCSC Part #
C1 | 0603 | 1 | 3u3 16V
D1 | 0603 | 1 | Led_green
J1 | ECV3-06 | 1 | Conn_01x06_Pin
J2 | PinHeader_2x06_P2.54mm_Vertical | 1 | Conn_02x06_Odd_Even
R1 | 0603 | 1 | 1k
R2 | 0603 | 1 | 10k
U1 | NC1000 | 1 | NC1000C-8

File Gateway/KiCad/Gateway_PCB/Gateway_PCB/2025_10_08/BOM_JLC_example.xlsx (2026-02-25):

Comment | Designator | Footprint | JLCPCB Part #（optional）
100uF | C1 | CAP-SMD_L3.5-W2.8 | C16133
15K | R5,R6 | R0603 | C22809
DC-005-20A_C136744 | DC1 | DC-IN-TH_DC-005-20A | C136744
Header-Female-2.54_1x8 | P2,P3 | HDR-TH_8P-P2.54-V | C27438
K2-1102DP-C4SW-04 | SW1 | KEY-TH_4P-L6.0-W6.0-P4.50-LS6.5 | C110153
ATMEGA328P-PU | U1 | DIP-28_L34.6-W7.3-P2.54-LS10.2-BL | C33901
670688000 | USB1 | USB-B-TH_67068-8000 | C114097

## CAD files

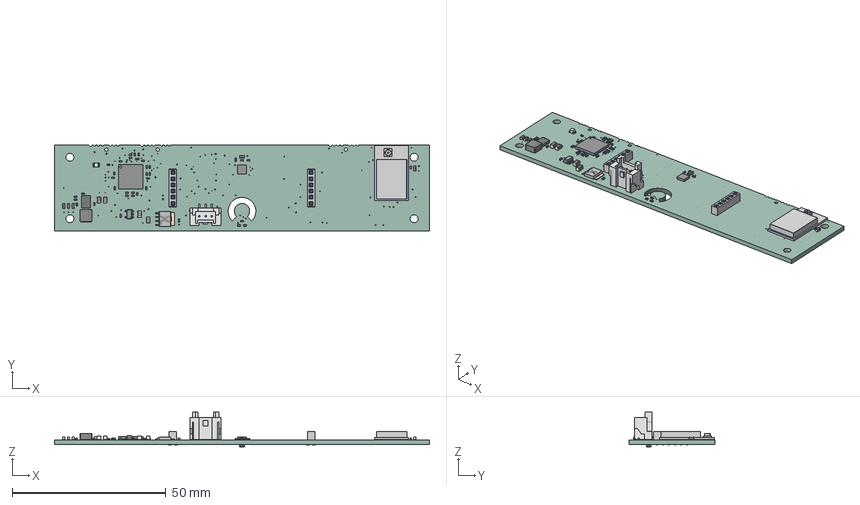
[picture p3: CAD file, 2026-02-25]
Actuator/KiCad/Main_PCB_Based_on_8411A/Main_PCB_Based_on_8411A.step
122.0 x 28.0 x 11.4 mm
BODY-QFN
PIN1-ID
R_0402_1005Metric x 12
NC1000C-8
C_0402_1005Metric x 24
C_0805_2012Metric x 4
XAL4020
C_0603_1608Metric x 5
MOLD
BM03B
PinsArrayL
PinsArrayR
Diepad_1
Solder1
TiNiAg_S_3
Clip_G
clip
Solder_CA_2_1
FM20C06VBNN x 2
LED_0805_2012Metric
CY8C5888LTQ-LP097
SHT45
Main_PCB_Based_on_8411A_PCB

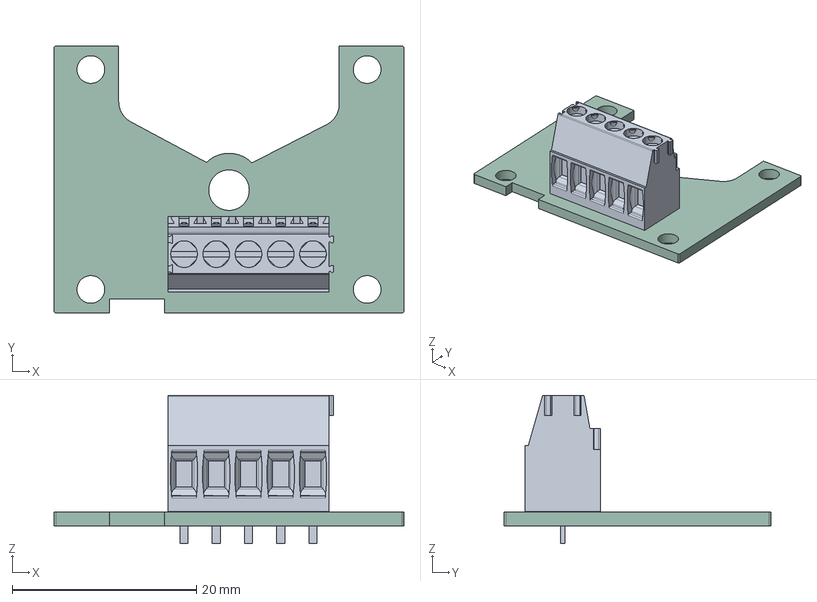
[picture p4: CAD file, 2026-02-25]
Actuator/KiCad/End_PCB_terminal_holder/End_PCB_terminal_holder.step
38.0 x 29.0 x 16.1 mm
End_PCB_terminal_holder_PCB

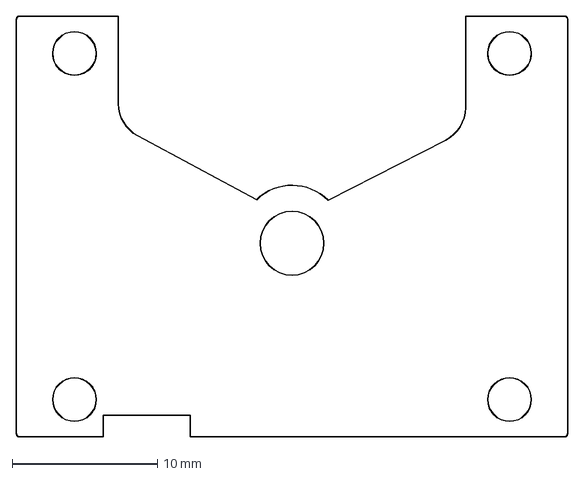
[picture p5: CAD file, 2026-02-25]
Actuator/KiCad/End_PCB_terminal_holder/Sketch42.dxf
38.0 x 29.0 mm

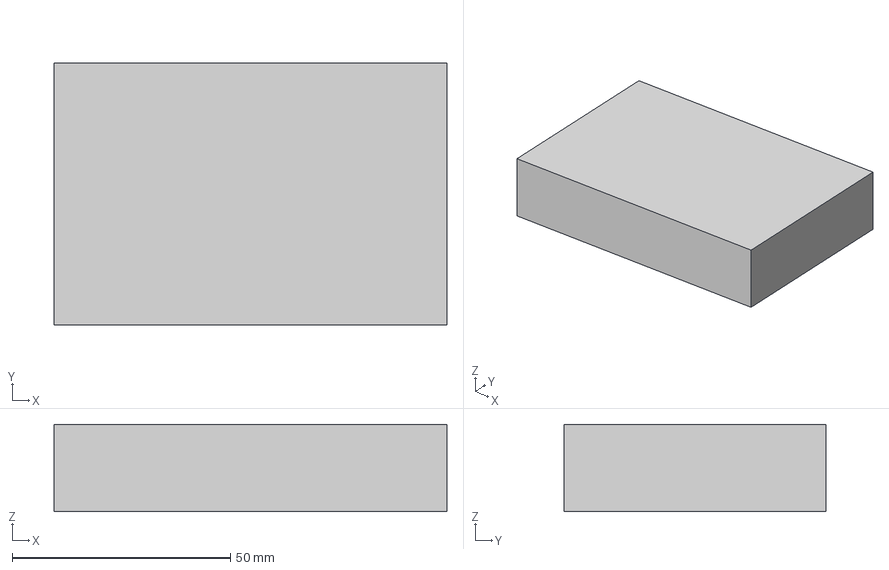
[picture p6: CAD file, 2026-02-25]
Actuator/KiCad/Main_PCB_Based_on_8411A/Enclosure_simplified v1.step
90.0 x 60.0 x 20.0 mm

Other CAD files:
Actuator/KiCad/Main_PCB_Based_on_8411A/Antenna_868.f3d

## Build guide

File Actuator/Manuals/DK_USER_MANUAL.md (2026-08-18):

# Energy Flow Wall — Demo Unit User Manual

**For the Denmark team. First-time setup and operation of the shipped prototype.**

---

## 1. What's in the Box

1. **1× Actuator** — the window-frame-mounted unit itself. Contains PSoC5 + NC1000 mesh radio + 2 motors + 2 flaps + fan + built-in T/H sensor. Runs on 1× rechargeable 18650 cell (**not provided** — you'll need to source one).
2. **1× Gateway** — Raspberry Pi 5 with NeoCortec NC1000 mesh daughter board on top. Supplied with EU-compatible power supply.
3. **3× Xiaomi LYWSD03MMC room sensors** (custom ATC firmware). They aren't physically labelled — Node-RED maps them to **Kitchen**, **Bedroom** and **Living** by MAC address. **Shipped without batteries** — you need **3× CR2032**.

**You will need to provide:**
- 1× rechargeable 18650 cell for the actuator (3.2 V LiFePO₄, 3.7 V Li-ion, or 4.2 V all work) + a suitable charger.
- 3× CR2032 coin cells for the Xiaomi room sensors.
- 1× Ethernet cable to connect the Gateway to your router.

---

## 2. First-time Setup (5 minutes)

### 2.1 Gateway
1. **Plug an Ethernet cable** from the Gateway into a free port on your router.
2. Plug the supplied power supply into the Gateway and into the wall.
3. Wait ~60 seconds for it to boot (green LED activity).

### 2.2 Actuator
1. Insert a charged 18650 cell into the actuator's battery holder (+ side in the direction marked on the holder). Polarity protection is fitted so a reversed cell won't damage anything, but it won't run either.
2. Power should come up automatically when the cell is seated.
3. On first power-up it runs an **auto-homing cycle** — the flaps move to both end-stops then park in the centre. Takes ~60 seconds. Normal. If you hear motor noise right after power-up, that's the auto-homing.

### 2.3 Room Sensors
1. Open each Xiaomi sensor (gentle pry on the case seam, no screws).
2. Insert a CR2032 battery (+ side up).
3. Close the case. Screen should display temperature + humidity after a few seconds.
4. Place in the rooms you want monitored.

---

## 3. Accessing the System

### 3.1 Control Dashboard — **Valve + Fan + Demo Mode**

Open in any browser on the same network:

**`http://rp5.local:1880/dashboard/valve-control-v2`**

If `rp5.local` doesn't resolve in Chrome or Brave (some browsers bypass `.local` DNS), use the IP instead:

**`http://10.0.0.123:1880/dashboard/valve-control-v2`**

Safari resolves `.local` natively.

### 3.2 Graphs — **Temperature + Humidity history**

**`http://rp5.local:3000`**

Login: a view-only Grafana account has been provided separately (see the email accompanying this manual).

Direct deep link to the NeoCortec board:
**`http://rp5.local:3000/d/170ba90a-9986-4e36-bd84-e81960c5e9b9/neocortec`**

---

## 4. Using the Control Dashboard

### 4.1 Valve Sliders
- **V1 slider** (0-100%) — Valve 1 position. 0 = fully closed end-stop, 100 = fully open end-stop. Moves the flap.
- **V2 slider** — Valve 2, same.
- **Fan slider** — fan speed, 0 (off) to 100 (max).

Slide and release. Command is queued and executed within a few seconds.

### 4.2 HOME button
Click **HOME** if the flaps ever look misaligned (unlikely but possible after a mechanical disturbance). It re-homes both valves. Takes ~60 seconds per valve. Turns green **HOMED OK** when done.

You can also home individual valves with **H1** and **H2** buttons.

### 4.3 Demo Mode
Click the **DEMO** button (grey, bottom of the page). It turns green **"DEMO ON"**.

In Demo Mode the system automatically follows the **room with the highest humidity** (Kitchen / Bedroom / Living / the actuator's own sensor). It drives the V1 valve position and Fan speed based on which room is "winning".

To test, breathe on one of the sensors for 5-10 seconds — humidity spikes, that sensor wins, the unit reacts within 30 s.

Click the button again to turn Demo Mode off.

### 4.4 Status Display

At the top of the page:
- **TX / RX** — last command sent and last reply received.
- **Pending** — commands queued.
- **Queue** — names of queued commands.
- **ALT / Normal** indicator — yellow when the mesh is in ALT mode (commands being sent), green when in Normal mode (sensors reporting).

---

## 5. Typical Usage Flow

1. Power everything on, wait for auto-homing to finish (~60 s).
2. Open dashboard — valves should show "HOMED OK" (green).
3. Drive V1 and V2 manually to see them work.
4. Insert room sensor batteries — watch them appear in the Grafana graphs.
5. Enable Demo Mode — observe the system respond to room humidity changes.

---

## 6. Troubleshooting

### "rp5.local" doesn't work
- Try `http://10.0.0.123` instead (IP fallback).
- Chrome and Brave sometimes bypass `.local` DNS. Safari always works.
- Confirm the Gateway is plugged into Ethernet and has a green link light.

### Dashboard shows **"NOT HOMED YET — click to home"**
- Press the **HOME** button. Wait ~90 s.
- If it ends with red "FAILED" or "COUPLER / ENC / MOTOR FAIL", something mechanical is off — send us a photo or video and we'll diagnose.

### Demo Mode doesn't react to sensor changes
- Confirm the room sensors have CR2032 batteries installed (screens show T/H).
- Check Grafana graphs — sensor data updates every ~15 s when healthy.
- Demo Mode only reacts when the *winner changes*. Small humidity differences may not flip the winner.

### Actuator battery flat
- Remove the 18650 and charge it in your Li-ion charger. 3.2 V LiFePO₄, 3.7 V Li-ion, and 4.2 V cells all work (development has been done on a 3.2 V LiFePO₄ 1800 mAh).
- Reinsert, it'll auto-home on power-up.

### Flaps make noise or sound harsh
- One valve uses a 250:1 gear ratio and the other 380:1 — they sound slightly different. Intentional, so you can compare and help inform the production choice. Final production gear ratio is **TBD**.

---

## 7. Contact

**Aidas Janulis** — a.janulis@gmail.com

Include in bug reports: screenshot of dashboard, screenshot of Grafana for the last hour, brief description. Happy to help over email or a quick video call.

---

## 8. Notes for DK Control-Algorithm Development

A separate technical document with the full command set (mesh protocol, AAPI ports, firmware commands, pipeline MQTT topics) will be shared directly with the person leading the control algorithm work. This keeps this user manual focused on operation rather than internals.

Dashboard-level commands sufficient for end-user operation:
- `V1,<0-100>` — valve 1 position %
- `V2,<0-100>` — valve 2 position %
- `F,<0-100>` — fan speed %
- `H` / `H1` / `H2` — home both / valve 1 / valve 2

These can be issued directly via MQTT (`efw/cmd/request` topic) if the dashboard UI is limiting.

---

*Document version: 2026-04-23 — matches shipped firmware v2.3.42 and pipeline/dashboard as of the same date.*

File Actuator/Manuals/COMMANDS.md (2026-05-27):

# Energy Flow Wall — Command Reference

**Complete CLI / MQTT / firmware command reference.** Intended for developers and integrators. End-user operation is covered in [`DK_USER_MANUAL.md`](DK_USER_MANUAL.md).

---

## How to Issue Commands

All commands reach the PSoC firmware via the same pipeline:

```
You → MQTT (efw/cmd/request) → efw-pipeline → NeoGateway (TCP) → NC1000 mesh → PSoC UART
```

Three ways to send a command:

### 1. Interactive CLI (on the RP5)

```
ssh rp5.local
/home/aidas/efw-pipeline/venv/bin/python /home/aidas/efw-pipeline/efw_cli.py
```

You'll get a prompt like `efw>`. Type commands directly (see reference below). The CLI wraps MQTT for you and shows state transitions + replies.

### 2. Direct MQTT publish

From anywhere that can reach the broker (RP5 port 1883):

```bash
mosquitto_pub -t efw/cmd/request -m '{"id":"my-1","cmd":"V1","arg":"50","timeout_s":30}'
```

JSON fields:
- `id` (string) — unique ID you choose; echoed back in status/result
- `cmd` (string) — command name (see reference)
- `arg` (string, optional) — command argument
- `timeout_s` (number, optional) — override default command timeout
- `priority` (bool, optional) — jump the queue (reserved for FORCE_NORMAL etc.)
- `retries` (number, optional) — number of auto-retries on timeout (default 1)

### 3. Dashboard (Valve Control v2)

The user-facing buttons/sliders in `http://rp5.local:1880/dashboard/valve-control-v2` translate to the same MQTT requests.

---

## MQTT Topics

| Topic | Direction | Purpose |
|---|---|---|
| `efw/cmd/request` | in → pipeline | Submit a command |
| `efw/cmd/status` | pipeline → out | State transitions: `queued` / `alt_on` / `sent` / `executed` / `alt_off` / `done` / `timeout` / `failed` |
| `efw/cmd/result` | pipeline → out | Terminal result with `outcome`: `ok` / `fail` / `timeout` and `reply` (firmware response string) |
| `efw/demo/enable` | in → demo brain | Toggle Demo Mode on/off (boolean payload) |
| `efw/demo/status` | demo brain → out | Demo Mode heartbeat text (winner + RH dump) |
| `efw/demo/rh/kitchen`, `/bedroom`, `/living` | Theengs/MQTT → demo brain | BLE sensor RH feed |

---

## Firmware Command Reference

Grouped by purpose. All values are **ASCII strings** sent via AAPI 0x03 on port 4. Replies arrive on port 4 from the actuator. All replies must fit in **21 bytes** (NC1000 AAPI payload limit).

### Queries (no argument)

| Command | Reply | Notes |
|---|---|---|
| `V`  | `v2.3.42` | Firmware version string |
| `HS` | `HS=<v1>,<v2>` | Homing status per valve. Each field: `OK` / `NONE` / `COUPLER` / `ENC` / `MOTOR` / `FAIL` |
| `TR` | `TR=<m1_tr>,<m2_tr>` | Travel counts from EEPROM per motor |
| `V1` / `V2` | `V1=<pct>` / `V2=<pct>` | Current position as percent of travel (integer, truncated) |
| `F`  | `F=<pct>` | Current fan percent |
| `S1` / `S2` | `S1=<pwm>` / `S2=<pwm>` | Current motor PWM (0-255) |
| `T1` / `T2` | `T1=<val>` / `T2=<val>` | Per-motor OCP threshold VDAC8 value (0-255) |
| `T0` | `T0=<val>` | Startup T boost (added to T1/T2 for TD ms after M_Go) |
| `TD` | `TD=<ms>` | Duration of startup T0 boost (0-500 ms) |
| `GCC` | `GCC=<val>` | Global current ceiling (DRV8411A VREF) VDAC8_3 value (0-255) |
| `M1` / `M2` | `M1=<counts>` / `M2=<counts>` | Current absolute position, relative to `g_zero` (signed) |
| `SR` | (sets internal variable) | Read Status register snapshot |

### Valve Position (percent)

| Command | Arg | Behaviour |
|---|-----|---|
| `V1,<0-100>` | percent | Drive M1 to `(pct × tr / 100)` counts. Reply: `V1=<actual_pct>,<stop>` where `<stop>` = `Q`/`S`/`O`/`F`/`T`/`t`/`?` |
| `V2,<0-100>` | percent | Same for M2 |

Stop codes:
- `Q` — reached target (success)
- `S` — stalled short of target (watchdog fired)
- `O` — OCP tripped (current > T)
- `F` — nFAULT (DRV8411A hardware fault)
- `T`/`t` — inrush phase timeout (Phase 1 = T too high / Phase 2 = T too low)
- `?` — unknown stop reason

If the valve hasn't been homed, reply is `V1=NOT_HOMED`.

### Fan Speed (percent)

| Command | Arg | Behaviour |
|---|-----|---|
| `F,<0-100>` | percent | 0 = fan off. 1..100 maps non-linearly to PWM 38..255 (so "1 %" is already the minimum smooth-running speed — below 38 the fan stutters). Reply: `F=<pct>` |

### Homing

| Command | Reply (success) | Reply (fault) | Notes |
|---|---|---|---|
| `H` | `H=OK` | `H=FAIL` | Home both valves. Success also emits per-motor `H1=OK,s,t,tr` + `H2=OK,s,t,tr` first |
| `H1` | `H1=OK,<s>,<t>,<tr>` | `H1=BROKEN_COUPLER` / `H1=ENC_FAIL` / `H1=MOTOR_FAIL` / `H1=FAIL` | Home valve 1 only |
| `H2` | `H2=OK,<s>,<t>,<tr>` | (same pattern) | Home valve 2 only |

Auto-home runs iteration loop: find min S where homing + 3-move validation pass, save `<s>`, `<t>`, `<tr>` to EEPROM, final re-home at `s_good`, park at `tr/2` (centre). Duration typically 30-90 s depending on motor/iteration count.

### Motor Control (raw, for dev / calibration)

**Prefer `V1` / `V2` for normal use.** M1/M2 take raw encoder counts, which are
**not comparable between motors** — the DK demo unit ships with mixed gear
ratios (M1: 250:1, full travel ≈ 715 counts; M2: 380:1, full travel ≈ 1095
counts), so `M1,500` ≈ 70 % open while `M2,500` ≈ 46 % open. V1/V2 divide
internally by each motor's stored travel range and stay correct across
hardware swaps.

| Command | Arg | Behaviour |
|---|-----|---|
| `M1,<counts>` | signed int16 | Drive M1 to absolute position `<counts>` relative to `g_zero`. Reply: `M1=<actual>,<stop>` |
| `M2,<counts>` | signed int16 | Same for M2 |
| `M1,32768` / `M2,32768` | (special) | **Emergency stop** — wraps to -32768 = immediate QuadDec UNDERFLOW, SRFF resets, motor stops instantly |

**Never use `M1,32766` or `M2,32766` for stop** — those are real targets (move 32766 counts). Only `32768` triggers the overflow stop trick.

### Motor PWM (speed, triggers CALT when set)

| Command | Arg | Behaviour |
|---|-----|---|
| `S1,<0-255>` | PWM value | Sets `g_m1_pwm`, then runs CALT to find new T1 threshold at this speed. Reply: `S1=<pwm>,T=<new_t>` or `S1=<pwm>,CALT_FAIL` |
| `S2,<0-255>` | PWM value | Same for M2 |
| `S1,+<delta>` / `S1,-<delta>` | relative | Add or subtract from current PWM |
| `S2,+<delta>` / `S2,-<delta>` | relative | Same for M2 |

CALT takes ~5-10 s (sweeps T to find minimum that lets the motor run).

### OCP Threshold (dev only — `S1,N` / `S2,N` auto-sets these)

| Command | Arg | Behaviour |
|---|-----|---|
| `T1,<0-255>` | VDAC8 value | Directly sets M1 OCP threshold. `I_trip = val × 0.008 A` (val × 16 mV / 10 kΩ / 200 µA·A⁻¹) |
| `T2,<0-255>` | VDAC8 value | Same for M2 |

**Warning:** setting T too low → OCP trips during normal running; too high → OCP never fires, motor can stall without detection. Normally auto_home + `S1,N` manage these for you.

### Calibration

| Command | Arg | Behaviour |
|---|-----|---|
| `CALT` / `CALT1` / `CALT2` | none | Calibrate minimum T for motor 1, 2, or both. Runs short 12-step test moves, alternating direction, with T sweeping from 25 up until motor runs without tripping, then sweeps back down to find the edge. Result stored in `g_calt_min1` / `g_calt_min2` |
| `CALMIN` | none | Calibrate minimum PWM that keeps motor moving (per-motor). Takes 10-30 s |
| `INRUSH1` / `INRUSH2` | none | Capture inrush phase timing. Reply includes t1/t2 ms for that motor's last run |

### Advanced / Debug

| Command | Arg | Behaviour |
|---|-----|---|
| `T0,<0-50>` | value | Startup T boost (added to T1/T2 for the first TD ms of a move, helps overcome stiction) |
| `TD,<0-500>` | ms | Duration of the T0 boost |
| `D,<0-1000>` | ms | Gate delay (diagnostic only — normally 0). Formerly used during OCP gate-open tuning |
| `GCC,<0-255>` | VDAC8 | Global current ceiling. `I_max = val × 0.008 A`. Default 125 = 1.0 A |
| `RP` / `RT` / `RS` | none | Set report type: Position / Threshold / Speed — changes `build_status()` output on next reply |
| `ZP` / `ZP1` / `ZP2` | none | Zero position (both / motor 1 / motor 2) — captures current `QuadDec_1/2` as new `g_zero`. **Not typically useful on its own** — auto_home sets zeros correctly |

### Emergency Stop

```
M1,32768    ← stops motor 1 immediately
M2,32768    ← stops motor 2 immediately
```

These wrap to `-32768` in int16 which fires an immediate QuadDec UNDERFLOW ISR, resetting the motor SRFF. Use these if a move is stuck or you want to abort.

---

## FORCE_NORMAL (Pipeline-level, not firmware)

Cancel whatever command is in flight and return to Normal mesh mode immediately. Sent via MQTT:

```bash
mosquitto_pub -t efw/cmd/request -m '{"id":"fn-1","cmd":"FORCE_NORMAL","priority":true}'
```

Also accessible via the dashboard Emergency Stop button (if wired).

---

## Useful MQTT Command Recipes

**Find current firmware version:**
```bash
mosquitto_pub -t efw/cmd/request -m '{"id":"v1","cmd":"V","timeout_s":15}'
mosquitto_sub -C 1 -t efw/cmd/result
```

**Open both valves to 100 %, fan max:**
```bash
for cmd in '"V1","arg":"100"' '"V2","arg":"100"' '"F","arg":"100"'; do
  mosquitto_pub -t efw/cmd/request -m "{\"id\":\"c$RANDOM\",\"cmd\":$cmd}"
  sleep 8
done
```

**Home both valves:**
```bash
mosquitto_pub -t efw/cmd/request -m '{"id":"h1","cmd":"H","timeout_s":180}'
```

**Query stored travel (useful after homing):**
```bash
mosquitto_pub -t efw/cmd/request -m '{"id":"tr1","cmd":"TR"}'
```

**Enable Demo Mode:**
```bash
mosquitto_pub -t efw/demo/enable -m 'true'
```

---

## Default Command Timeouts (from `CMDS` dict in `efw_pipeline.py`)

| Cmd | Timeout | Cmd | Timeout |
|-----|---|-----|---|
| `V`, `F`, `S1/2`, `T1/2`, `T0`, `TD`, `GCC` | 10 s | `HS`, `TR`, `TL` | 10 s |
| `M1`, `M2`, `V1`, `V2` | 30 s | `ZP`, `ZP1`, `ZP2` | 10 s |
| `H1`, `H2` | 60 s | `H` | 90 s |
| `CALT`, `CALMIN`, `INRUSH*` | depends — use long `timeout_s` override in MQTT payload | | |

---

## Notes on Payload Limits

NC1000 AAPI payloads are hard-capped at **21 bytes** in both directions. All firmware replies fit inside this (e.g. `H1=OK,80,39,709` = 15 chars). If you add new commands, keep replies short.

Integer-percent rounding in `V1`/`V2` replies means small discrepancies between commanded and reported position are normal (e.g. command `V1,50` at a motor parked at 346/715 counts reports `V1=48` because `346 × 100 / 715 = 48.39 → 48` integer truncation).

---

*Document version: 2026-04-23 — matches firmware v2.3.42 and pipeline as of the same date.*

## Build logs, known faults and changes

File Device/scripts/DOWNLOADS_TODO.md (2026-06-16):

# EFW Device — Documents Still To Download Manually

Generated by `grab_datasheets.py`. Direct downloads completed by the script are in their respective subfolders.

Click the URLs below in a browser — most fail under curl because of CDN protection (ST), gated downloads (Infineon, Nordic), or login walls.

## 02_Display_Touch

- **SSD1683_controller_datasheet.pdf**
  Often embedded in the GoodDisplay panel spec PDF; if not, search "SSD1683 datasheet PDF".

## 03_Sensors

- **BGT60LTR11AIP_app_note_autonomous_mode.pdf**
  Same Infineon page → Application Notes → autonomous mode AN. Priority for our use case.

## 04_Power

- **LFP143060_spec.pdf**
  Vendor (lithium-lifepo4-battery.com) will email the spec with the sample order.

## 05_Mesh

- **NC1000_datasheet.pdf**
  Copy from your existing NeoCortec docs folder (already in hand from Actuator work).

- **NeoCortec_AAPI_specification.pdf**
  Copy from your existing NeoCortec docs folder (AAPI spec + NcApi.c source already in hand).

## 06_Misc

- **LTV-356T_optocoupler.pdf**
  Search "LTV-356T datasheet PDF" — Lite-On part. Alternative: PC817 (Sharp) at https://www.farnell.com/datasheets/73758.pdf.

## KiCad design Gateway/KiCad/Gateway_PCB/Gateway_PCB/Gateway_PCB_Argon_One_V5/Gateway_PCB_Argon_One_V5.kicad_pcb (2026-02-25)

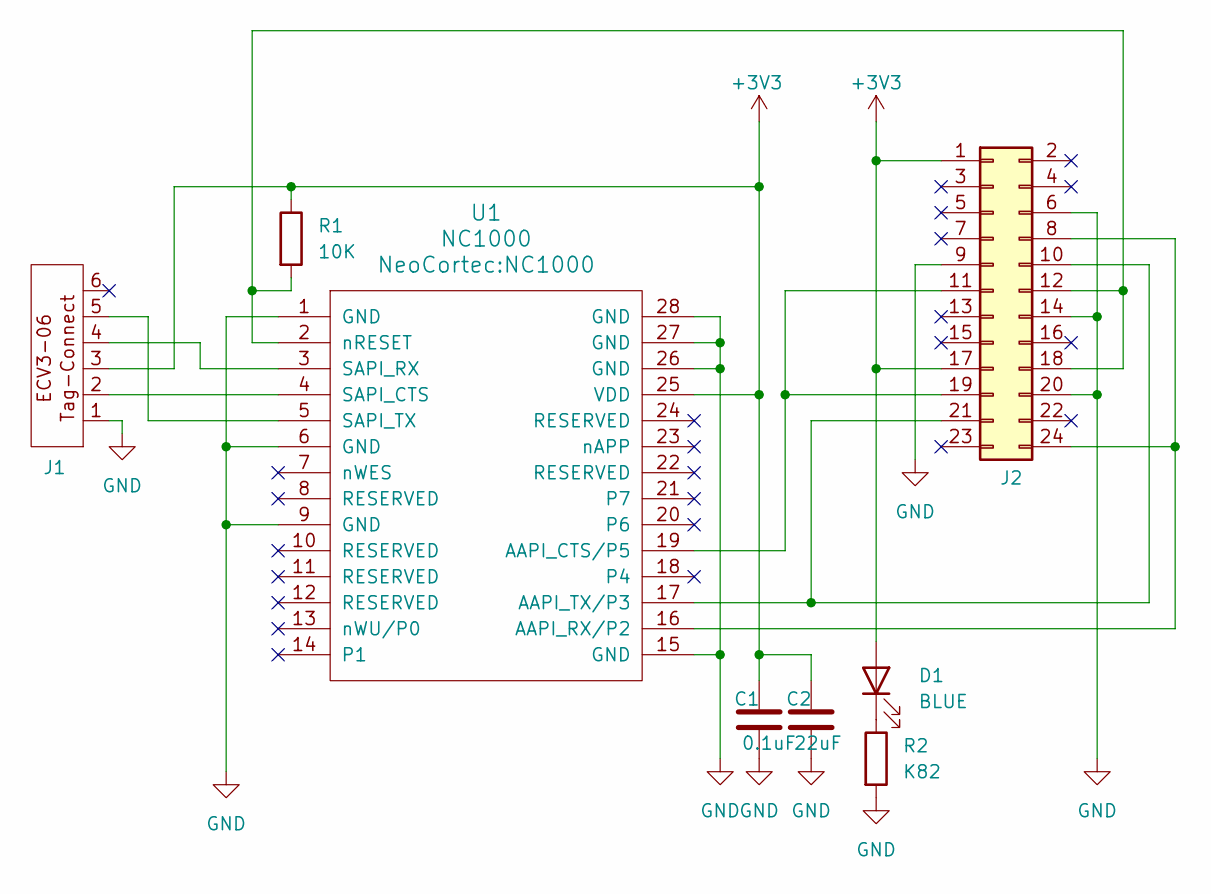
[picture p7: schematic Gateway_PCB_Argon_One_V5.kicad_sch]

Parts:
C1: 0.1uF; C_0402_1005Metric; JLCPCB Part # C77014
C2: 22uF; C_0603_1608Metric; JLCPCB Part # C77042
D1: BLUE; LED_0805_2012Metric; JLCPCB Part # C98222
J1: ECV3-06
J2: Conn_02x12_Odd_Even; PinHeader_2x12_P2.54mm_Vertical
R1: 10K; R_0402_1005Metric; JLCPCB Part # C25744
R2: K82; R_0402_1005Metric; JLCPCB Part # C25135
U1: NC1000

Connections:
+3V3: C1.1, C2.1, D1.2 (A), J1.3, J2.1, J2.17, R1.1, U1.25 (VDD)
GND: C1.2, C2.2, J1.1, J2.6, J2.9, J2.14, J2.20, R2.2, U1.1 (GND), U1.6 (GND), U1.9 (GND), U1.15 (GND), U1.26 (GND), U1.27 (GND), U1.28 (GND)
unnamed: D1.1 (K), R2.1
unnamed: J2.10, J2.21, U1.17 (AAPI_TX/P3)
unnamed: J2.11, J2.19, U1.19 (AAPI_CTS/P5)
unnamed: J2.12, J2.18, R1.2, U1.2 (nRESET)
unnamed: J2.8, J2.24, U1.16 (AAPI_RX/P2)
unnamed: J1.2, U1.4 (SAPI_CTS)
unnamed: J1.4, U1.3 (SAPI_RX)
unnamed: J1.5, U1.5 (SAPI_TX)

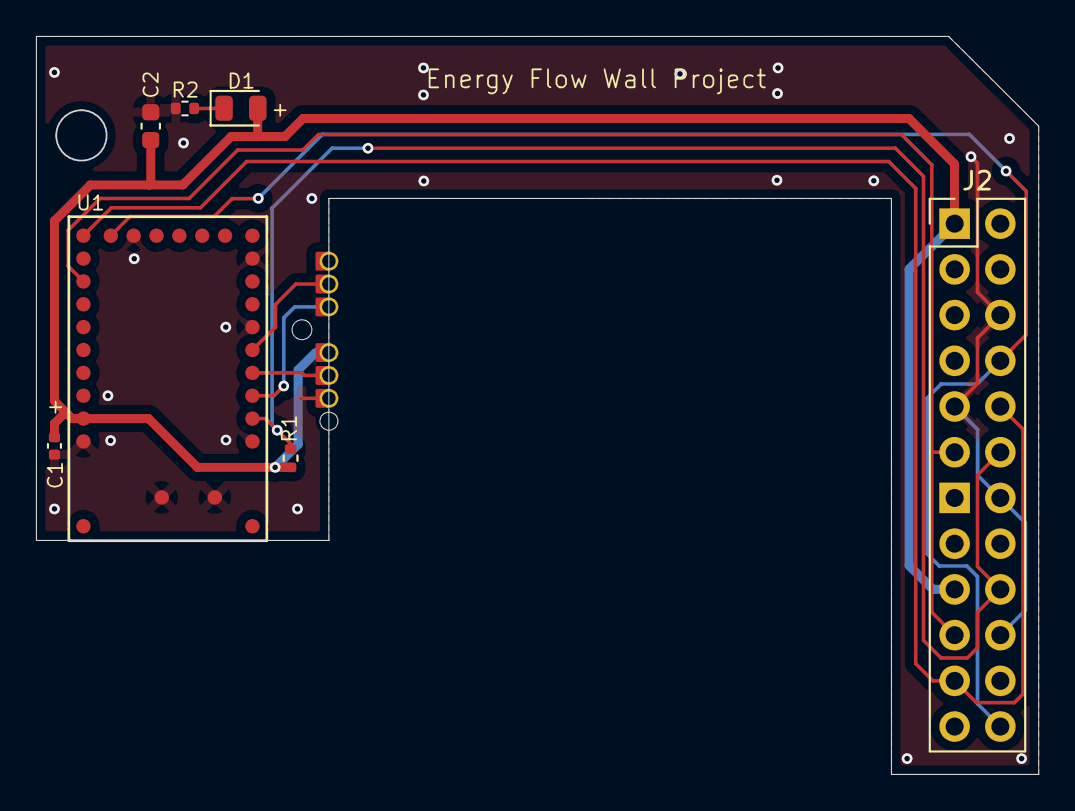
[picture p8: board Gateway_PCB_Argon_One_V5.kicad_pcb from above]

Board: 2 copper layers, 55.7 x 41.0 mm, 8 parts (1 on the bottom side), 10 nets.

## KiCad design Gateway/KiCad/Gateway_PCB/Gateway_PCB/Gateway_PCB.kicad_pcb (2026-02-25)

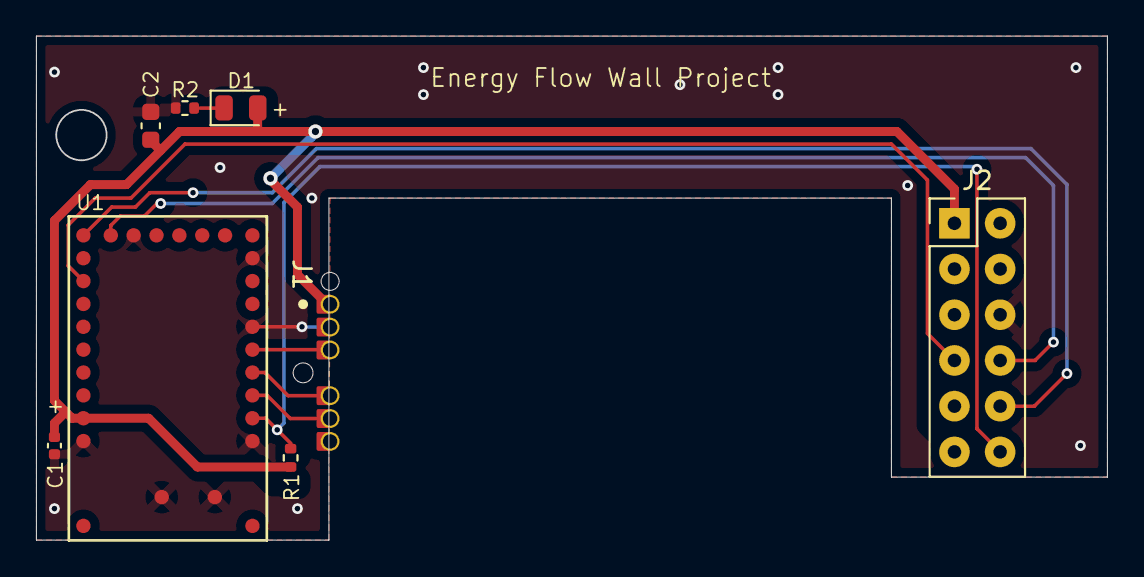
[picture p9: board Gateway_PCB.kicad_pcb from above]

Board: 2 copper layers, 59.5 x 28.0 mm, 8 parts (0 on the bottom side), 7 nets.

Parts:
C1: 0.1uF; C_0402_1005Metric
C2: 22uF; C_0603_1608Metric
D1: BLUE; LED_0805_2012Metric
J1: Conn_01x06_Pin; ECV3-06
J2: Conn_02x06_Odd_Even; PinHeader_2x06_P2.54mm_Vertical
R1: 10K; R_0402_1005Metric
R2: K82; R_0402_1005Metric
U1: NC1000

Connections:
+3V3: C1.1, C2.1, D1.2 (A), J1.1, J2.1, R1.2, U1.25 (VDD)
GND: C1.2, C2.2, J1.2, J2.6, J2.9, R2.2, U1.1 (GND), U1.6 (GND), U1.9 (GND), U1.15 (GND), U1.26 (GND), U1.27 (GND), U1.28 (GND)
unnamed: D1.1 (K), R2.1
unnamed: J2.7, U1.19 (AAPI_CTS/P5)
unnamed: J2.8, U1.16 (AAPI_RX/P2)
unnamed: J2.10, U1.17 (AAPI_TX/P3)
unnamed: J2.12, R1.1, U1.2 (nRESET)

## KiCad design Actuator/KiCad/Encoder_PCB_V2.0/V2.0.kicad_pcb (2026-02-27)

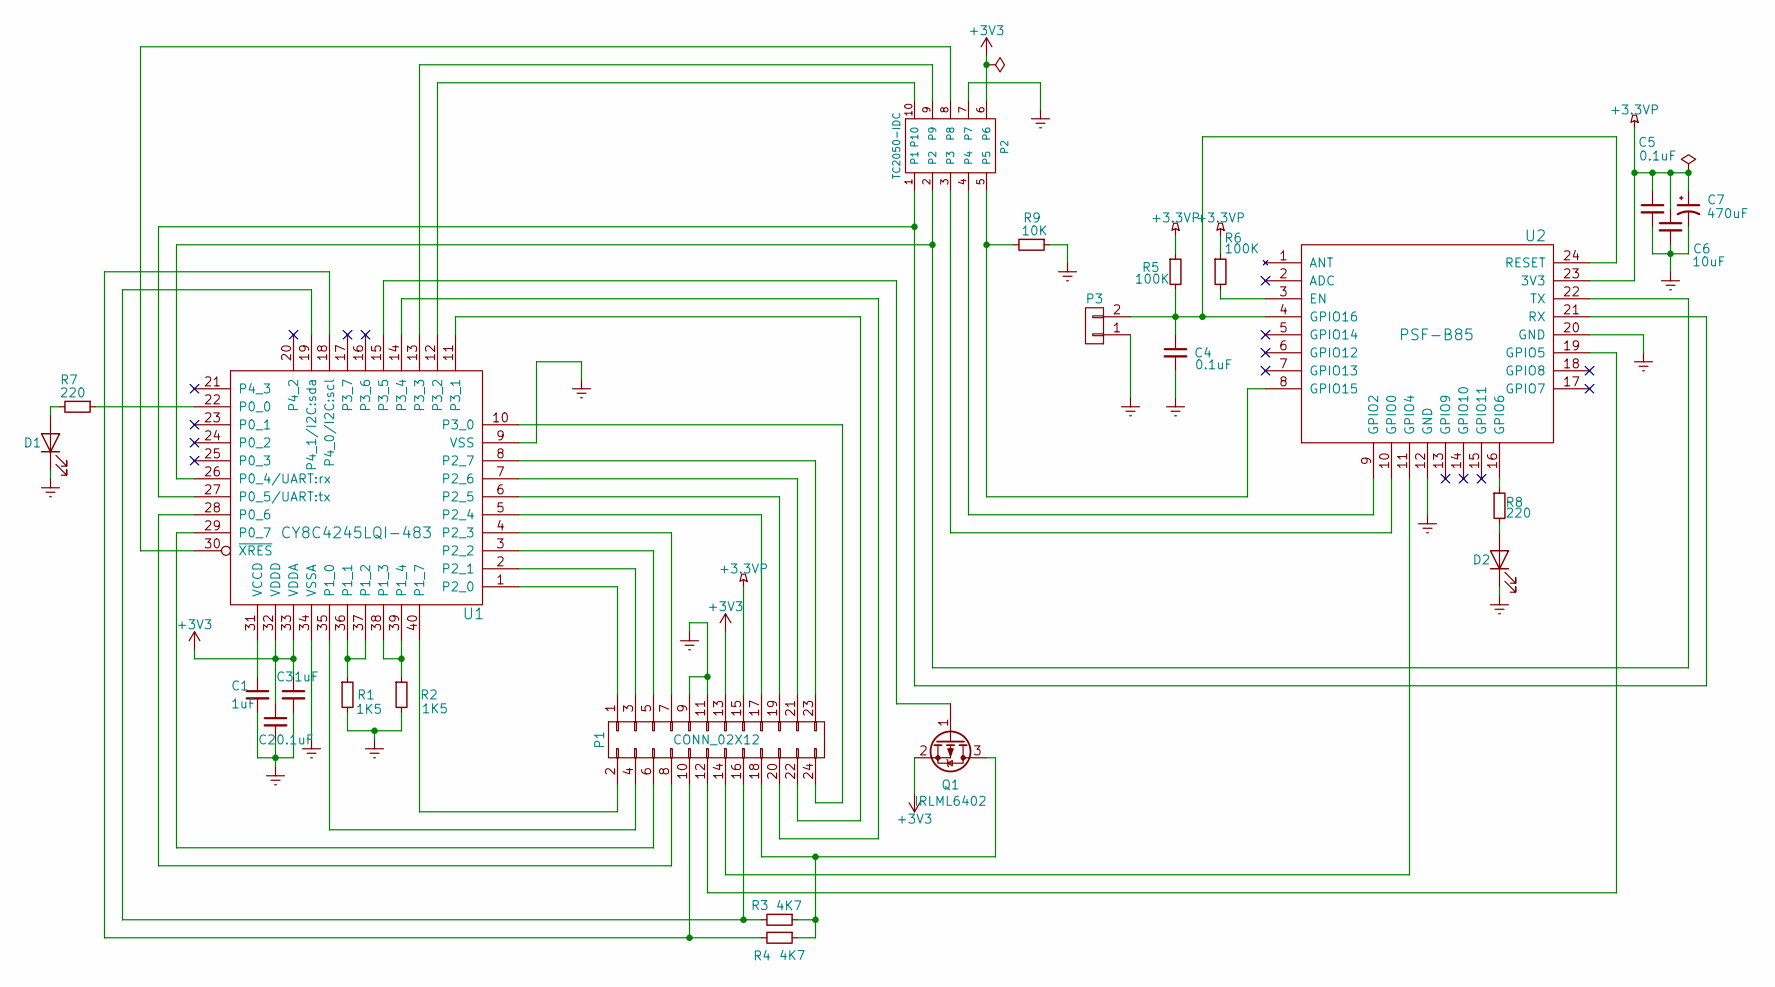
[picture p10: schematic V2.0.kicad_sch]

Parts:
C1, C3: 1uF; C_0603
C2, C4, C5: 0.1uF; C_0402
C6: 10uF; C_1206
C7: 470uF; CP_EIA-7343-31_Kemet-D_Pad2.25x2.55mm_HandSolder; MPN T520D477M006ATE030
D1, D2: LED; LED_0805_2012Metric; MPN MF-LED-0805-GREEN
P1: CONN_02X12; Pin_Header_Straight_2x12_Pitch1.27mm
P2: TC2050-IDC; TC2050-IDC_NL
P3: CONN_01X02; PinHeader_1x02_P2.54mm_Vertical
Q1: IRLML6402
R1, R2: 1K5; R_0603
R3, R4: 4K7; R_0603
R5, R6: 100K; R_0402
R7, R8: 220; R_0603_1608Metric; MPN MF-RES-0603-220
R9: 10K; R_0603_1608Metric; MPN MF-RES-0603-10
U1: CY8C4245LQI-483; QFN40-6x6
U2: PSF-B85

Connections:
+3.3VP: C5.1, C6.1, C7.1, P1.15, R5.1, R6.1, U2.23 (3V3)
+3V3: C2.1, C3.1, P1.13, P2.6, Q1.2 (S), U1.32 (VDDD), U1.33 (VDDA)
GNDREF: C1.2, C2.2, C3.2, C4.2, C5.2, C6.2, C7.2, D1.1 (K), D2.1 (K), P1.9, P1.11, P2.7, P3.1, R1.2, R2.2, R9.1, U1.9 (VSS), U1.34 (VSSA), U2.12 (GND), U2.20 (GND)
unnamed: C1.1, U1.31 (VCCD)
unnamed: C4.1, P3.2, R5.2, U2.4 (GPIO16), U2.24 (RESET)
unnamed: D1.2 (A), R7.2
unnamed: D2.2 (A), R8.2
unnamed: P1.1, U1.1 (P2_0)
unnamed: P1.2, U1.40 (P1_7)
unnamed: P1.3, U1.2 (P2_1)
unnamed: P1.4, U1.35 (P1_0)
unnamed: P1.5, U1.3 (P2_2)
unnamed: P1.6, U1.29 (P0_7)
unnamed: P1.7, U1.4 (P2_3)
unnamed: P1.8, U1.28 (P0_6)
unnamed: P1.10, R4.2, U1.18 (P4_0/I2C:scl)
unnamed: P1.12, U2.19 (GPIO5)
unnamed: P1.14, U2.11 (GPIO4)
unnamed: P1.16, R3.2, U1.19 (P4_1/I2C:sda)
unnamed: P1.17, U1.5 (P2_4)
unnamed: P1.18, Q1.3 (D), R3.1, R4.1
unnamed: P1.19, U1.6 (P2_5)
unnamed: P1.20, U1.14 (P3_4)
unnamed: P1.21, U1.7 (P2_6)
unnamed: P1.22, U1.11 (P3_1)
unnamed: P1.23, U1.8 (P2_7)
unnamed: P1.24, U1.10 (P3_0)
unnamed: P2.1, U1.27 (P0_5/UART:tx), U2.21 (RX)
unnamed: P2.2, U1.26 (P0_4/UART:rx), U2.22 (TX)
unnamed: P2.3, U2.10 (GPIO0)
unnamed: P2.4, U2.9 (GPIO2)
unnamed: P2.5, R9.2, U2.8 (GPIO15)
unnamed: P2.8, U1.30 (~XRES)
unnamed: P2.9, U1.13 (P3_3)
unnamed: P2.10, U1.12 (P3_2)
unnamed: Q1.1 (G), U1.15 (P3_5)
unnamed: R1.1, U1.36 (P1_1), U1.37 (P1_2)
unnamed: R2.1, U1.38 (P1_3), U1.39 (P1_4)
unnamed: R6.2, U2.3 (EN)
unnamed: R7.1, U1.22 (P0_0)
unnamed: R8.1, U2.16 (GPIO6)

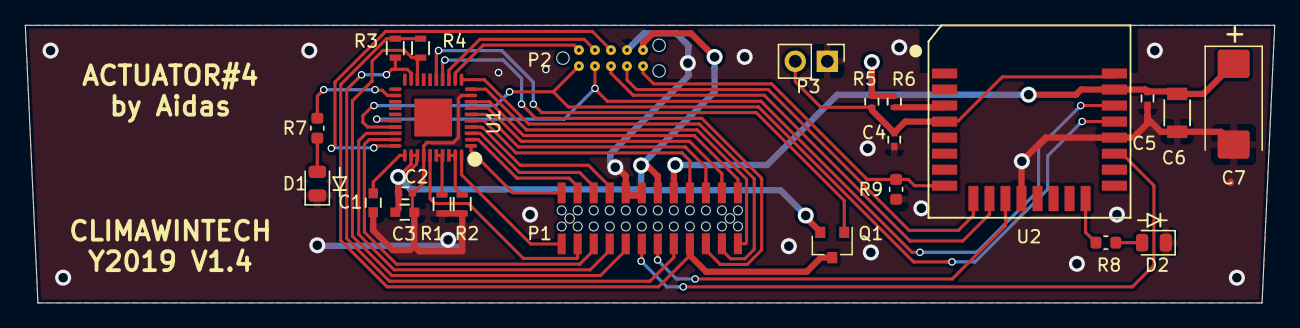
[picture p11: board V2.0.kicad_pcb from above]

Board: 2 copper layers, 99.0 x 22.0 mm, 24 parts (0 on the bottom side), 41 nets.

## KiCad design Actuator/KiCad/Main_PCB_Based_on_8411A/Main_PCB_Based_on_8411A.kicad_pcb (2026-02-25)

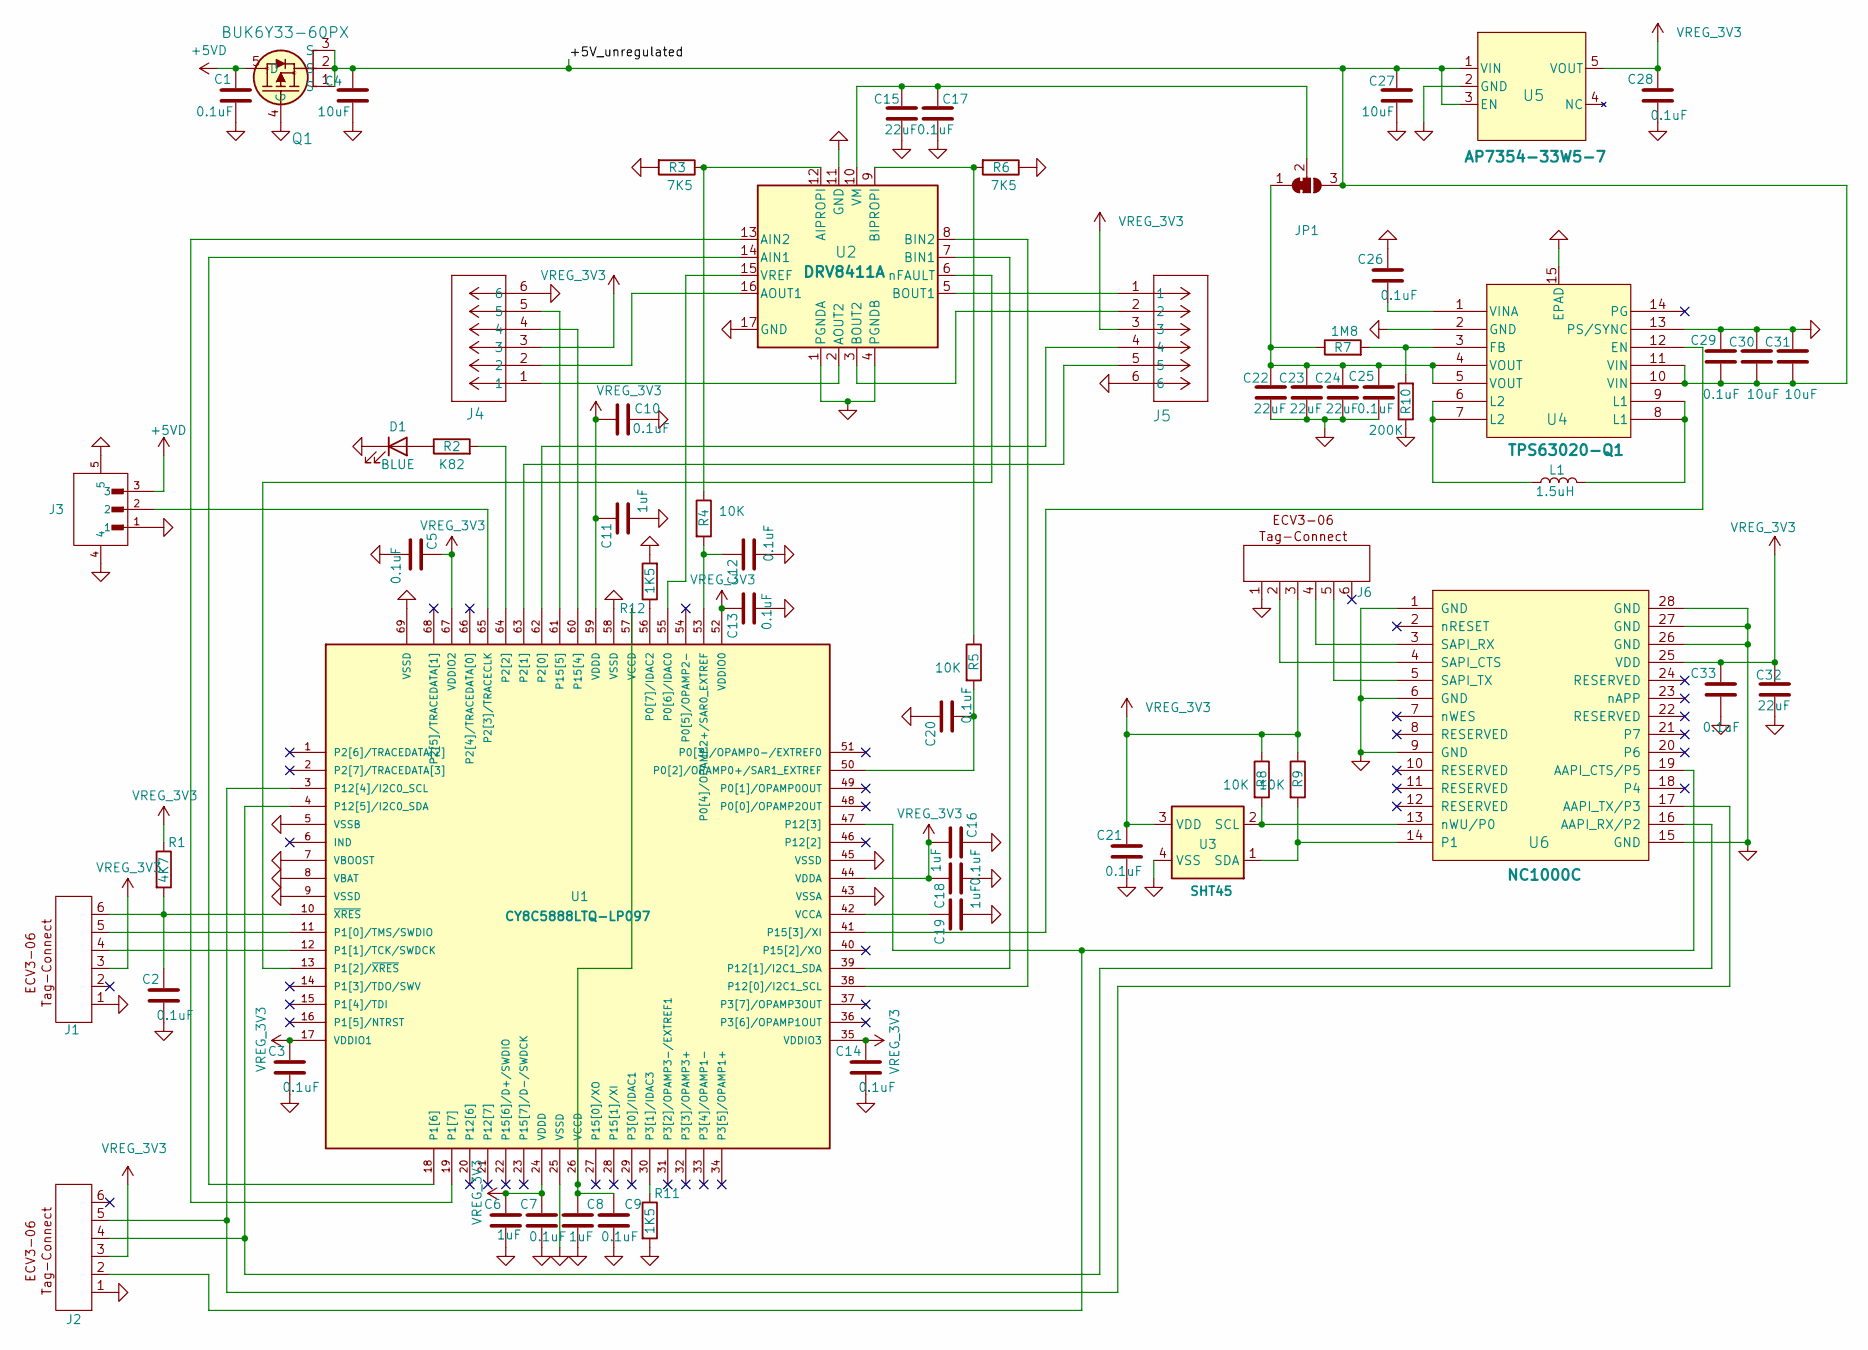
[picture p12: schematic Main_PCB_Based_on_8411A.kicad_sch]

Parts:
C1, C2, C3, C5, C7, C9, C10, C12, C13, C14, C17, C18, C20, C21, C25, C26, C28, C29, C33: 0.1uF; C_0402_1005Metric; MFR.Part # GRM155R71E104KE14D; JLCPCB Part # C77014
C4, C27, C30, C31: 10uF; C_0805_2012Metric; MFR.Part # GRM21BR71C106KE51L; JLCPCB Part # C408142
C6, C8, C11, C16, C19: 1uF; C_0402_1005Metric; MFR.Part # GRM155Z71A105KE01D; JLCPCB Part # C528974
C15, C22, C23, C24, C32: 22uF; C_0603_1608Metric; MFR.Part # GRM188R60J226MEA0D; JLCPCB Part # C77042
D1: BLUE; LED_0805_2012Metric; MFR.Part # LTST-C170TBKT; JLCPCB Part # C98222
J1, J2, J6: ECV3-06
J3: BM03B-PASS-1-TFT; JST_BM03B-PASS-1-TFT; PARTREV FEB.14.2024; JLCPCB Part # C485351
J4, J5: FM20C06VBNN
JP1: SolderJumper_3_Bridged12; SolderJumper-3_P1.3mm_Bridged12_RoundedPad1.0x1.5mm
L1: 1.5uH; L_Coilcraft_XxL4020; MFR.Part # XAL4020-152MEC; JLCPCB Part # C18547833
Q1: BUK6Y33-60PX; LFPAK_SOT669_NEX
R1: 4K7; R_0402_1005Metric; MFR.Part # AC0402FR-7W4K7L; JLCPCB Part # C5455562
R2: K82; R_0402_1005Metric; MFR.Part # 0402WGF8200TCE; JLCPCB Part # C25135
R3: 7K5; R_0402_1005Metric; MFR.Part # AC0402FR-7W7K5L; JLCPCB Part # C6117685
R4, R5, R8, R9: 10K; R_0402_1005Metric; MFR.Part # 0402WGF1002TCE; JLCPCB Part # C25744
R6: 7K5; R_0402_1005Metric; MFR.Part # AC0402FR-7W3K9L; JLCPCB Part # C6117679
R7: 1M8; R_0402_1005Metric; MFR.Part # RC0402FR-071M8L; JLCPCB Part # C185447
R10: 200K; R_0402_1005Metric; MFR.Part # 0402WGF2003TCE; JLCPCB Part # C25764
R11, R12: 1K5; R_0402_1005Metric; MFR.Part # AC0402FR-7W1K5L; JLCPCB Part # C5575287
U1: CY8C5888LTQ-LP097; QFN40P800X800X100-69N; PARTREV L
U2: DRV8411A; WQFN16_RTE_TEX; MFR.Part # DRV8411ARTER; JLCPCB Part # C18816315
U3: SHT45; SHT45_C_cutout_clean_new; MFR.Part # SHT45-AD1F-R2; JLCPCB Part # C5360602
U4: TPS63020-Q1; TPS63020QDSJRQ1; MFR.Part # TPS63020QDSJRQ1; JLCPCB Part # C2876554
U5: AP7354-33W5-7; SOT25_AP7354_DIO; MFR.Part # AP7354-33W5-7; JLCPCB Part # C460386
U6: NC1000C; NC1000c

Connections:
+5VD: C1.2, J3.3, Q1.5 (D)
/+5V_unregulated: C4.1, C27.1, C29.1, C30.2, C31.2, JP1.3 (B), Q1.1 (S), Q1.2 (S), Q1.3 (S), U4.10 (VIN), U4.11 (VIN), U5.1 (VIN), U5.3 (EN)
GND: C1.1, C2.1, C3.1, C4.2, C5.1, C6.1, C7.1, C8.1, C9.1, C10.1, C11.1, C12.1, C13.1, C14.1, C15.2, C16.2, C17.2, C18.1, C19.1, C20.2, C21.1, C22.2, C23.2, C24.2, C25.1, C26.2, C27.2, C28.1, C29.2, C30.1, C31.1, C32.2, C33.1, D1.1 (K), J1.1, J2.1, J3.1, J3.4, J3.5, J4.6, J5.6, J6.1, Q1.4 (G), R3.2, R6.1, R10.1, R11.2, R12.2, U1.5 (VSSB), U1.7 (VBOOST), U1.8 (VBAT), U1.9 (VSSD), U1.25 (VSSD), U1.43 (VSSA), U1.45 (VSSD), U1.58 (VSSD), U1.69 (VSSD), U2.1 (PGNDA), U2.4 (PGNDB), U2.11 (GND), U2.17 (GND), U3.4 (VSS), U4.2 (GND), U4.13 (PS/SYNC), U4.15 (EPAD), U5.2 (GND), U6.1 (GND), U6.6 (GND), U6.9 (GND), U6.15 (GND), U6.26 (GND), U6.27 (GND), U6.28 (GND)
unnamed: C8.2, C9.2, U1.26 (VCCD), U1.57 (VCCD)
unnamed: D1.2 (A), R2.1
unnamed: C22.1, C23.1, C24.1, C25.2, JP1.1 (A), R7.1, U4.4 (VOUT), U4.5 (VOUT)
unnamed: C15.1, C17.1, JP1.2 (C), U2.10 (VM)
unnamed: L1.1, U4.6 (L2), U4.7 (L2)
unnamed: L1.2, U4.8 (L1), U4.9 (L1)
unnamed: C20.1, R5.2, U1.50 (P0[2]/OPAMP0+/SAR1_EXTREF)
unnamed: C12.2, R4.2, U1.53 (P0[4]/OPAMP2+/SAR0_EXTREF)
unnamed: U1.55 (P0[6]/IDAC0), U2.15 (VREF)
unnamed: R12.1, U1.56 (P0[7]/IDAC2)
unnamed: J1.5, U1.11 (P1[0]/TMS/SWDIO)
unnamed: J1.4, U1.12 (P1[1]/TCK/SWDCK)
unnamed: U1.13 (P1[2]/~XRES), U2.6 (nFAULT)
unnamed: U1.18 (P1[6]), U2.14 (AIN1)
unnamed: U1.19 (P1[7]), U2.13 (AIN2)
unnamed: J5.4, U1.62 (P2[0])
unnamed: J5.5, U1.63 (P2[1])
unnamed: R2.2, U1.64 (P2[2])
unnamed: J3.2, U1.65 (P2[3]/TRACECLK)
unnamed: R11.1, U1.30 (P3[1]/IDAC3)
unnamed: U1.38 (P12[0]/I2C1_SCL), U2.8 (BIN2)
unnamed: U1.39 (P12[1]/I2C1_SDA), U2.7 (BIN1)
unnamed: J2.2, U1.47 (P12[3]), U6.19 (AAPI_CTS/P5)
unnamed: J2.5, U1.3 (P12[4]/I2C0_SCL), U6.17 (AAPI_TX/P3)
unnamed: J2.4, U1.4 (P12[5]/I2C0_SDA), U6.16 (AAPI_RX/P2)
unnamed: U1.41 (P15[3]/XI), U4.12 (EN)
unnamed: J4.4, U1.60 (P15[4])
unnamed: J4.5, U1.61 (P15[5])
unnamed: C19.2, U1.42 (VCCA)
unnamed: C2.2, J1.6, R1.2, U1.10 (~XRES)
unnamed: R3.1, R4.1, U2.12 (AIPROPI)
unnamed: J4.2, U2.16 (AOUT1)
unnamed: J4.1, U2.2 (AOUT2)
unnamed: R5.1, R6.2, U2.9 (BIPROPI)
unnamed: J5.1, U2.5 (BOUT1)
unnamed: J5.2, U2.3 (BOUT2)
unnamed: R8.2, U3.2 (SCL), U6.13 (nWU/P0)
unnamed: R9.2, U3.1 (SDA), U6.14 (P1)
unnamed: R7.2, R10.2, U4.3 (FB)
unnamed: C26.1, U4.1 (VINA)
unnamed: J6.2, U6.4 (SAPI_CTS)
unnamed: J6.4, U6.3 (SAPI_RX)
unnamed: J6.5, U6.5 (SAPI_TX)
VREG_3V3: C3.2, C5.2, C6.2, C7.2, C10.2, C11.2, C13.2, C14.2, C16.1, C18.2, C21.2, C28.2, C32.1, C33.2, J1.3, J2.3, J4.3, J5.3, J6.3, R1.1, R8.1, R9.1, U1.17 (VDDIO1), U1.24 (VDDD), U1.35 (VDDIO3), U1.44 (VDDA), U1.52 (VDDIO0), U1.59 (VDDD), U1.67 (VDDIO2), U3.3 (VDD), U5.5 (VOUT), U6.25 (VDD)

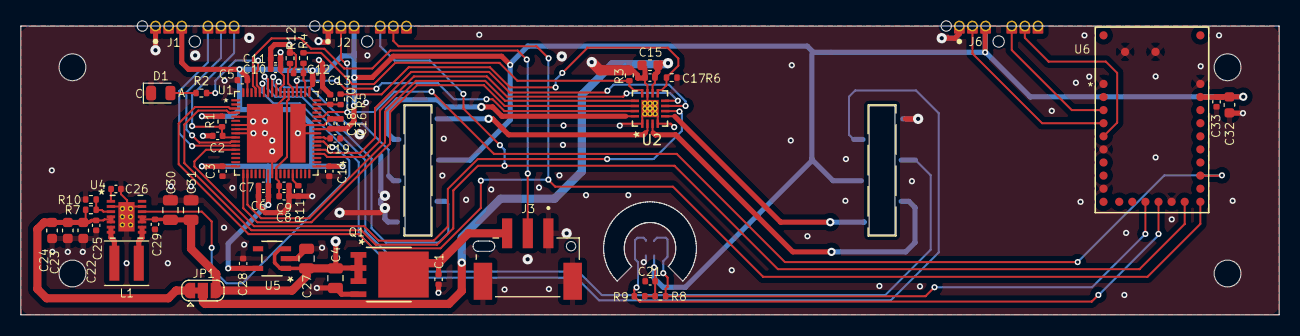
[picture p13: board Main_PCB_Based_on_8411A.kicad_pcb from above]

Board: 2 copper layers, 122.0 x 28.0 mm, 61 parts (1 on the bottom side), 47 nets.

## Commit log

2026-01-11 Initial commit: PSoC 5 LED control with power management
    - Add main.c with interrupt-driven LED control
    - Add comprehensive REFERENCE.md documentation
    - Add README.md with project overview
    - Implement deep sleep/hibernate mode
    - Support event-based state transitions
2026-01-11 Add TopDesign.cysch hardware configuration
    - Add PSoC Creator hardware schematic file
    - Defines InputPin, InputInterrupt, and OutputPinSW components
    - Hardware configuration for LED control and power management
2026-01-11 Add UART command control for LED patterns
    Features:
    - Implement LED:X:Y command parser via UART
    - Support variable blink count and frequency control
    - 115200 baud serial communication (8N1)
    - Command format: LED:blinks:frequency
    - Execute pattern then enter deep sleep
    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
2026-01-15 Working UART command parsing - simplified version
    Changes:
    - Remove sleep mode temporarily for testing
    - Disable interrupt handling (CTS shared with UART)
    - Implement full UART command parsing for LED:X:Y format
    - Add command buffering with newline termination
    - Successfully tested with NC1000 mesh network module
    - Update README with hardware connections and GND requirement
    Working features:
    - Normal 1Hz LED blinking
    - UART command reception and parsing
    - Variable blink patterns via LED:X:Y commands
    - Auto-resume to normal blinking after command
    Hardware fix:
    - CRITICAL: GND connection required between NC1000 and PSoC
    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
2026-01-15 Add Fusion 360 3D CAD model
    - Add mechanical design file for Energy Flow Wall actuator
    - Based on DRV8411A motor driver
    - Non-symmetrical case design version 4
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2026-01-15 Remove source code files - moved to private repository
    Code files now in private repo: Energy_Flow_Wall_Code
    This public repo contains only shareable CAD files.
2026-02-25 Add Functional Requirements Document v0.8
    - System overview and architecture
    - Gateway and actuator node specifications
    - Communication protocol details (Normal/Alternative modes)
    - Hardware reference (RPi 5, NC1000, PSoC, DRV8411A)
    - UART wiring and configuration
    - Known issues and development notes
2026-02-25 Add KiCad hardware designs
    - Main actuator PCB (DRV8411A-based motor controller)
    - Gateway PCB (RPi HAT for NC1000 module)
    - Power connectors PCB
    - End terminal holder PCB
    - Production files (Gerbers, BOMs, pick-and-place)
    Includes schematics, PCB layouts, and fabrication outputs.
    [Antenna_868.f3d, BOM_JLC_example.xlsx, Enclosure_simplified v1.step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]
2026-02-25 Remove unused Power_connectors PCB design
    This design is no longer used in the project.
    [Power_connectors.kicad_pcb, Power_connectors.kicad_sch, Power_connectors.step]
2026-02-27 Add Encoder PCB V2.0 KiCad design files
    Custom magnetic encoder board for Pololu Micro Metal Gearmotors
    (Pololu #3078, 250:1 HPCB 6V). Based on Pololu reference design,
    redesigned to fit flush on the motor. 12 CPR, Hall effect sensor
    (PSF-B85), A+B quadrature output.
    [V2.0.kicad_pcb, V2.0.kicad_sch]
2026-02-27 Add system reference document
    Comprehensive notes on hardware, firmware, mesh architecture,
    sensor formulas, command set, and homing sequence for the
    Energy Flow Wall actuator system.
2026-02-27 Update system reference: QuadDec overflow not a concern
    Full output shaft rotation ~6000 counts (2x decoding), max flap
    travel ~3000 counts — well within 16-bit counter range.
2026-02-28 Add PSoC5 hardware motor control architecture to system reference
    Documents SR flip-flop state machine (M1_Go/M2_Go), hardware M_Power
    control, Status register bit mapping, and confirmed PSoC Creator
    component API names from build artifacts.
2026-02-28 Update hardware section: add all BOM components, U designators, connectors
    - Add U1/U2/U3/U4 designators (were missing)
    - Add L1 = XAL4020-152MEC 1.5µH (TPS63020 inductor — was missing)
    - Add J3 = BM03B-PASS-1-TFT fan connector (was missing)
    - Add J1/J2/J6 = ECV3-06 Tag-Connect programming headers (were missing)
    - Add JP1 solder jumper
    - Add D1 exact part LTST-C170TBKT
    - Update Device node list to include 0x66
2026-02-28 Document JP1 motor power source selection jumper
    1-2 (default): battery → TPS63020 buck-boost → 5V motor rail
    2-3: regulated 5V supply → bypasses U4 entirely
2026-02-28 Add likely DNP caps for regulated supply variant (TBC)
    C22-C25, C29-C31 are probably TPS63020 filter caps, likely DNP
    when JP1 2-3 (regulated supply). Marked TBC pending schematic verify.
2026-02-28 Clarify DNP list for regulated supply: all U4 Vin/Vout decoupling caps confirmed
    C22-C24 (22uF bulk), C25/C26/C29 (0.1uF bypass), C30/C31 (10uF bulk)
    are all decoupling caps on U4 rails, confirmed DNP when JP1 2-3.
2026-02-28 Fix node type: 0x66 is Actuator not Device; placeholder for encoder sensor PN
2026-02-28 Fix encoder Hall sensor part number and Encoder PCB KiCad path
    - Correct Hall sensor: PSF-B85 → TLE4946-2K (Infineon, SOT-23) — confirmed from production BOM
    - Fix Encoder PCB KiCad path to correct local project location
    - Add 0x66 to SHT45 sensor formula entry (same formula as 0x55)
2026-02-28 Add encoder power switching design note for next PCB revision
    Power encoders from TPS63020 5V (auto-switched by M_Power, no FET needed).
    Add 8x voltage divider resistors on main PCB (5.6K+10K per signal) to level-shift
    open-drain outputs from 5V to 3.2V for PSoC. Encoder PCB unchanged.
    Update Hall_Pwr note accordingly.
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2026-03-12 Add NeoCortec documentation to Docs/NeoCortec/
    - Neo.Gateway-User-Guide-v1.3.pdf
    - NeoCortec Communication Specification System UART v2.0.pdf
    - Integration Manual for NCxxxx series Modules v3.2.pdf
    - NEOCORTEC-NC1000-Datasheet-V1.5.pdf
2026-05-27 Fix DK manual: Ethernet cable not in box, sensors not physically labelled
    §1: removed Ethernet cable from box contents (not actually shipped) and
    added it to the "you will need to provide" list. Clarified that the
    Kitchen/Bedroom/Living labels live in Node-RED (MAC-mapped), not on the
    sensors themselves.
    §2.1: "the Ethernet cable" → "an Ethernet cable" for consistency.
2026-05-27 Clarify M1/M2 raw-count caveats in COMMANDS.md
    Note that M1/M2 counts are not comparable between motors (DK unit ships
    with mixed 250:1 / 380:1 gear ratios → different full-travel ranges) and
    that V1/V2 percent commands are the portable, motor-agnostic abstraction.
    Catches a likely footgun for new integrators.
2026-05-31 Drop stale 0x66 references in SYSTEM_REFERENCE.md
    The Actuator NC1000 mesh node ID is 0x55, not 0x66. 0x66 was a temporary
    ID during early bring-up; verified 2026-05-31 against the live RP5 flows
    and the shipping efw_pipeline.py default.
2026-06-16 Add Device design intent, prep work, and procurement notes
    Device is the third EFW node type (alongside Gateway and Actuator):
    battery-powered in-room sensor + e-paper UI with NeoCortec mesh and
    Bluetooth Low Energy. Hardware not yet designed; this commit captures
    the locked architectural decisions, datasheet stash plan, and dev-kit
    shopping list before PCB layout begins.
    Contents under Hardware/Device/:
    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
2026-06-16 Add display-touch porting guide + HTML manual-downloads index
    Hardware/Device/Docs/ now holds two author-written annotations about
    the external reference materials kept locally. The third-party PDFs
    and vendor sample-code .rar archives stay out of the repo.
    - Docs/02_Display_Touch/READ_FIRST.md port strategy from GoodDisplay
    GDEY042T81-T02 STM32F103 sample
    firmware to the STM32U585 target
    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
2026-08-18 Restructure repo by subsystem: Actuator / Gateway / Device
    Hardware/KiCad, the Fusion 360 case file, and the Actuator manuals move
    under Actuator/. Docs/NeoCortec (protocol docs the Gateway pipeline
    implements against) moves under Gateway/. Hardware/Device promotes to
    top-level Device/. Docs/ keeps only whole-system docs (functional
    requirements, system reference). Fixed the two relative links in
    Device/README.md that assumed the old two-levels-deep path, and updated
    its now-stale "firmware will land there" note (it already has).
    [Antenna_868.f3d, BOM_JLC_example.xlsx, Enclosure_simplified v1.step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]
2026-08-18 Move Gateway_PCB (RPi/NC1000 HAT) from Actuator/ to Gateway/
    Was grouped under Actuator/KiCad/ by mistake -- it's the Gateway's own
    daughterboard, not part of the Actuator unit. Now at Gateway/KiCad/.
    [BOM_JLC_example.xlsx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]
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2026-08-18 Fix terminology: window-frame-mounted, not wall-mounted
